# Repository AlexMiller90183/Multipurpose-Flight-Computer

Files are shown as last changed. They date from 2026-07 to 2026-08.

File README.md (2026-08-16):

Multipurpose Flight Computer
============================
This project is a flight computer designed to be used for many purposes, whether it be RC airplanes, model rockets, or even drones. Because of the broad usage capability it's designed to be as small as possible. It includes a barometer, IMU, servo outputs, and a battery controller. It is all powered by the STM32



PCB:
====
Schematic:
opdf-1





Why this?
=========
Well there I was... sitting bored at home

Just kidding. I previously made an Arduino Nano based flight computer with premade components and it was my first ever PCB! As I've learned more though, I wanted to challenge myself with something a little more complex and this was the perfect idea! I followed @NotARoomba's tutorial, but tried to make my version as small and compact as possible.

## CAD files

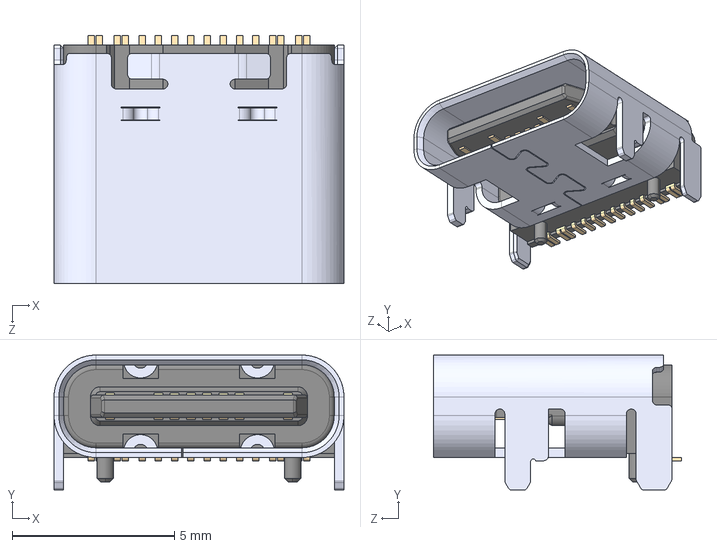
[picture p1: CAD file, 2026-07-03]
external 3d models/TYPE-C 16PIN 2MD -073---3DModel-STEP-740413.STEP
8.94 x 4.16 x 7.65 mm

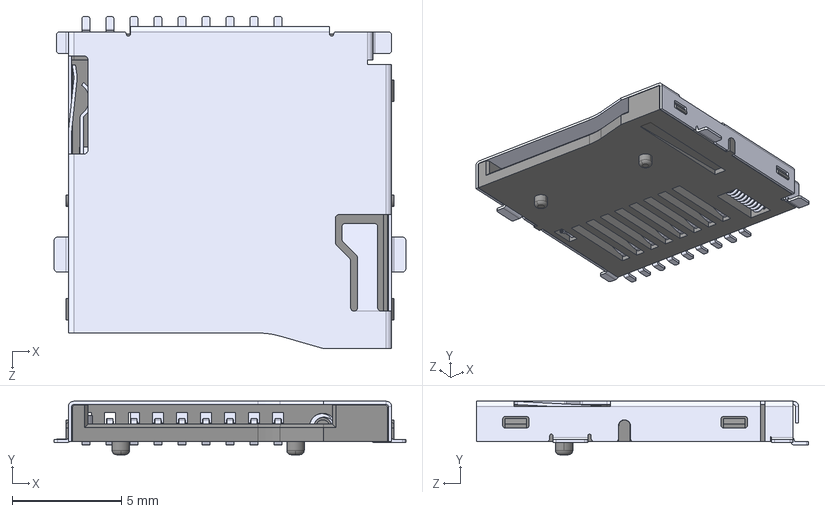
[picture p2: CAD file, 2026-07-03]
external 3d models/TF-01A--3DModel-STEP-56544.STEP
16.1 x 2.45 x 15.2 mm

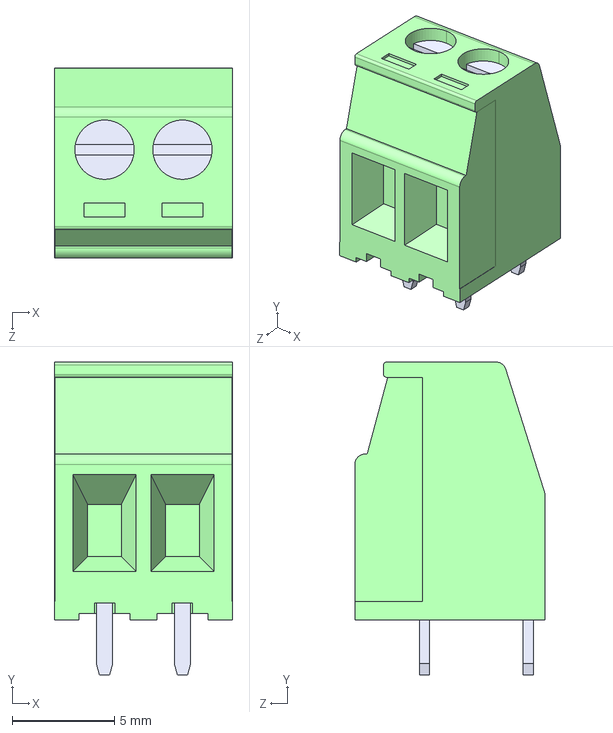
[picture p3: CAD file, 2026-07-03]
external 3d models/MKDS 1_ 2-3.81.STEP
8.71 x 15.3 x 9.30 mm

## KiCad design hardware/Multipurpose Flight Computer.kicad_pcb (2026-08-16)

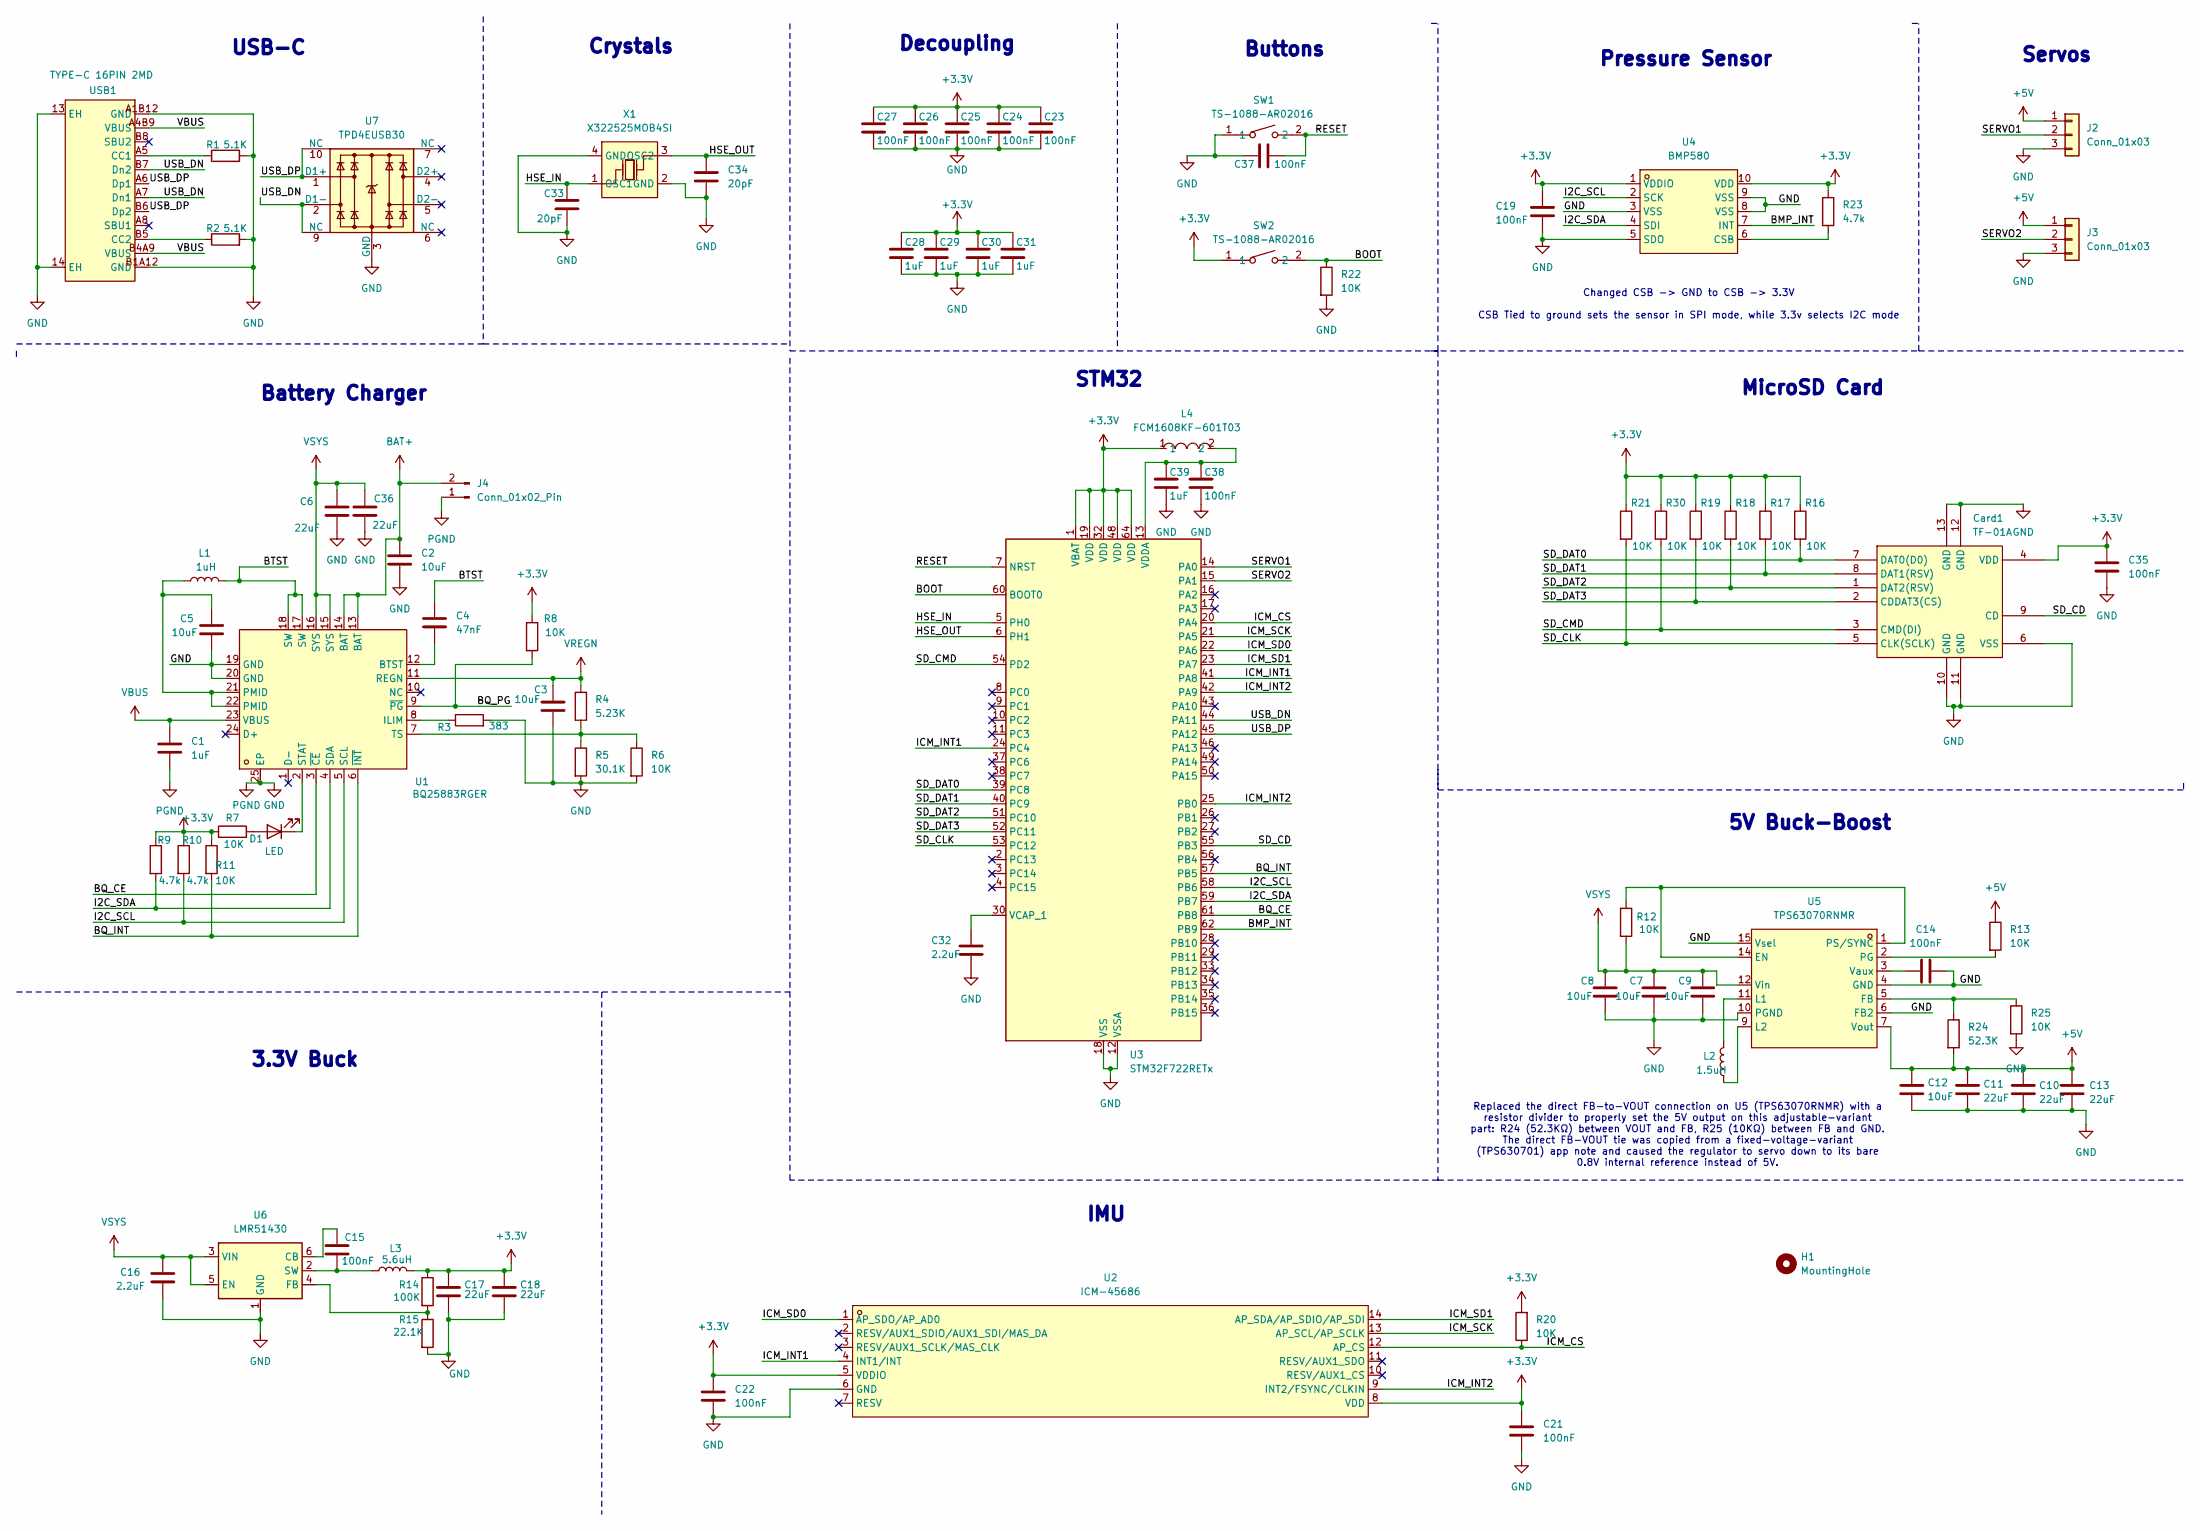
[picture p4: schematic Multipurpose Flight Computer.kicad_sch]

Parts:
C1, C28, C29, C30, C31, C39: 1uF; C_0402_1005Metric
C2, C12: 10uF; C_0603_1608Metric
C3, C5: 10uF; C_0402_1005Metric
C4: 47nF; C_0201_0603Metric
C6, C36: 22uF; C_0603_1608Metric
C7, C8, C9: 10uF; C_0805_2012Metric
C10, C11, C13: 22uF; C_0805_2012Metric
C14, C15, C19, C21, C22, C23, C24, C25, C26, C27, C35, C37, C38: 100nF; C_0201_0603Metric
C16: 2.2uF; C_0603_1608Metric
C17, C18: 22uF; C_0402_1005Metric
C32: 2.2uF; C_0201_0603Metric
C33, C34: 20pF; C_0201_0603Metric
Card1: TF-01A; TF-SMD_TF-01A; MPN TF-01A; LCSC Part C91145
D1: LED; LED_0402_1005Metric
H1: MountingHole; MountingHole_2.2mm_M2_DIN965_Pad_TopBottom
J2, J3: Conn_01x03; PinHeader_1x03_P2.54mm_Vertical
J4: Conn_01x02_Pin; CONN-TH_XT30PW-M
L1: 1uH; L2520
L2: 1.5uH; IND-SMD_L4.0-W4.0-A
L3: 5.6uH; IND-SMD_L3.0-W3.0
L4: FCM1608KF-601T03; L0603; MPN FCM1608KF-601T03; LCSC Part C141723
R1, R2: 5.1K; R_0201_0603Metric
R3: 383; R_0603_1608Metric
R4: 5.23K; R_0201_0603Metric
R5: 30.1K; R_0402_1005Metric
R6, R7, R8, R11, R12, R13, R16, R17, R18, R19, R20, R21, R22, R25, R30: 10K; R_0201_0603Metric
R9, R10, R23: 4.7k; R_0201_0603Metric
R14: 100K; R_0402_1005Metric
R15: 22.1K; R_0402_1005Metric
R24: 52.3K; R_0201_0603Metric
SW1, SW2: TS-1088-AR02016; SW-SMD_L3.9-W3.0-P4.45; MPN TS-1088-AR02016; LCSC Part C720477
U1: BQ25883RGER; VFQFPN-24_L4.0-W4.0-P0.50-BL-EP2.8; MPN BQ25883RGER; LCSC Part C544362
U2: ICM-45686; LGA-14_L3.0-W2.5-P0.50-TL; MPN ICM-45686; LCSC Part C22459454
U3: STM32F722RETx; LQFP-64_10x10mm_P0.5mm
U4: BMP580; LGA-10_L2.0-W2.0-P0.50-TL_BMP580; MPN BMP580; LCSC Part C22391138
U5: TPS63070RNMR; VQFN-15_L3.0-W2.5-P0.50-BL; MPN TPS63070RNMR; LCSC Part C109322
U6: LMR51430; SOT-23-6
U7: TPD4EUSB30; USON-10_2.5x1.0mm_P0.5mm
USB1: TYPE-C 16PIN 2MD; USB-C-SMD_TYPE-C-16PIN-2MD-073; MPN TYPE-C 16PIN 2MD(073); LCSC Part C2765186
X1: X322525MOB4SI; CRYSTAL-SMD_4P-L3.2-W2.5-BL; MPN X322525MOB4SI; LCSC Part C9006

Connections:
+3.3V: C17.1, C18.1, C19.1, C21.1, C22.1, C23.1, C24.1, C25.1, C26.1, C27.1, C28.1, C29.1, C30.1, C31.1, C35.2, Card1.4 (VDD), L3.2, L4.1, R7.1, R8.1, R9.1, R10.1, R11.1, R14.1, R16.1, R17.1, R18.1, R19.1, R20.2, R21.1, R23.1, R30.1, SW2.1, U2.5 (VDDIO), U2.8 (VDD), U3.1 (VBAT), U3.19 (VDD), U3.32 (VDD), U3.48 (VDD), U3.64 (VDD), U4.1 (VDDIO), U4.10 (VDD)
+5V: C10.1, C11.1, C12.1, C13.1, J2.1, J3.1, R13.1, R24.2, U5.7 (Vout)
/BMP_INT: U3.62 (PB9), U4.7 (INT)
/BOOT: R22.1, SW2.2, U3.60 (BOOT0)
/BQ_CE: U1.3 (~CE), U3.61 (PB8)
/BQ_INT: R11.2, U1.6 (~INT), U3.57 (PB5)
/BQ_PG: R8.2, U1.9 (~PG)
/BTST: C4.1, L1.2, U1.17 (SW), U1.18 (SW)
/HSE_IN: C33.1, U3.5 (PH0), X1.1 (OSC1)
/HSE_OUT: C34.1, U3.6 (PH1), X1.3 (OSC2)
/I2C_SCL: R10.2, U1.5 (SCL), U3.58 (PB6), U4.2 (SCK)
/I2C_SDA: R9.2, U1.4 (SDA), U3.59 (PB7), U4.4 (SDI)
/ICM_CS: R20.1, U2.12 (AP_CS), U3.20 (PA4)
/ICM_INT1: U2.4 (INT1/INT), U3.24 (PC4), U3.41 (PA8)
/ICM_INT2: U2.9 (INT2/FSYNC/CLKIN), U3.25 (PB0), U3.42 (PA9)
/ICM_SCK: U2.13 (AP_SCL/AP_SCLK), U3.21 (PA5)
/ICM_SD0: U2.1 (AP_SDO/AP_AD0), U3.22 (PA6)
/ICM_SD1: U2.14 (AP_SDA/AP_SDIO/AP_SDI), U3.23 (PA7)
/RESET: C37.1, SW1.2, U3.7 (NRST)
/SD_CD: Card1.9 (CD), U3.55 (PB3)
/SD_CLK: Card1.5 (CLK(SCLK)), R21.2, U3.53 (PC12)
/SD_CMD: Card1.3 (CMD(DI)), R30.2, U3.54 (PD2)
/SD_DAT0: Card1.7 (DAT0(D0)), R16.2, U3.39 (PC8)
/SD_DAT1: Card1.8 (DAT1(RSV)), R17.2, U3.40 (PC9)
/SD_DAT2: Card1.1 (DAT2(RSV)), R18.2, U3.51 (PC10)
/SD_DAT3: Card1.2 (CDDAT3(CS)), R19.2, U3.52 (PC11)
/SERVO1: J2.2, U3.14 (PA0)
/SERVO2: J3.2, U3.15 (PA1)
/USB_DN: U3.44 (PA11), U7.2 (D1-), U7.9 (NC), USB1.A7 (Dn1), USB1.B7 (Dn2)
/USB_DP: U3.45 (PA12), U7.1 (D1+), U7.10 (NC), USB1.A6 (Dp1), USB1.B6 (Dp2)
BAT+: C2.1, J4.2, U1.13 (BAT), U1.14 (BAT)
GND: C1.2, C2.2, C3.2, C5.2, C6.2, C7.2, C8.2, C9.2, C10.2, C11.2, C12.2, C13.2, C14.2, C16.2, C17.2, C18.2, C19.2, C21.2, C22.2, C23.2, C24.2, C25.2, C26.2, C27.2, C28.2, C29.2, C30.2, C31.2, C32.2, C33.2, C34.2, C35.1, C36.2, C37.2, C38.2, C39.2, Card1.6 (VSS), Card1.10 (GND), Card1.11 (GND), Card1.12 (GND), Card1.13 (GND), J2.3, J3.3, J4.1, R1.2, R2.2, R3.2, R5.2, R6.2, R15.2, R22.2, R25.2, SW1.1, U1.19 (GND), U1.20 (GND), U1.25 (EP), U2.6 (GND), U3.12 (VSSA), U3.18 (VSS), U3.31 (VSS), U3.47 (VSS), U3.63 (VSS), U4.3 (VSS), U4.5 (SDO), U4.8 (VSS), U4.9 (VSS), U5.4 (GND), U5.6 (FB2), U5.10 (PGND), U5.15 (Vsel), U6.1 (GND), U7.3 (GND), U7.8 (GND), USB1.13 (EH), USB1.14 (EH), USB1.A1B12 (GND), USB1.B1A12 (GND), X1.2 (GND), X1.4 (GND)
unnamed: C5.1, L1.1, U1.21 (PMID), U1.22 (PMID)
unnamed: D1.2 (A), R7.2
unnamed: D1.1 (K), U1.2 (STAT)
unnamed: C4.2, U1.12 (BTST)
unnamed: R3.1, U1.8 (ILIM)
unnamed: R4.2, R5.1, R6.1, U1.7 (TS)
unnamed: C32.1, U3.30 (VCAP_1)
unnamed: C38.1, C39.1, L4.2, U3.13 (VDDA)
unnamed: R23.2, U4.6 (CSB)
unnamed: R12.1, U5.1 (PS/SYNC), U5.14 (EN)
unnamed: R24.1, R25.1, U5.5 (FB)
unnamed: L2.2, U5.11 (L1)
unnamed: L2.1, U5.9 (L2)
unnamed: R13.2, U5.2 (PG)
unnamed: C14.1, U5.3 (Vaux)
unnamed: C15.1, U6.6 (CB)
unnamed: R14.2, R15.1, U6.4 (FB)
unnamed: C15.2, L3.1, U6.2 (SW)
unnamed: R1.1, USB1.A5 (CC1)
unnamed: R2.1, USB1.B5 (CC2)
VBUS: C1.1, U1.23 (VBUS), USB1.A4B9 (VBUS), USB1.B4A9 (VBUS)
VREGN: C3.1, R4.1, U1.11 (REGN)
VSYS: C6.1, C7.1, C8.1, C9.1, C16.1, C36.1, R12.2, U1.15 (SYS), U1.16 (SYS), U5.12 (Vin), U6.3 (VIN), U6.5 (EN)

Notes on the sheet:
STM32
Crystals
3.3V Buck
USB-C
Replaced the direct FB-to-VOUT connection on U5 (TPS63070RNMR) with a resistor divider to properly set the 5V output on this adjustable-variant part: R24 (52.3KΩ) between VOUT and FB, R25 (10KΩ) between FB and GND. The direct FB-VOUT tie was copied from a fixed-voltage-variant (TPS630701) app note 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
IMU
MicroSD Card
Servos
Decoupling
Battery Charger
Buttons
5V Buck-Boost
Changed CSB -> GND to CSB -> 3.3V CSB Tied to ground sets the sensor in SPI mode, while 3.3v selects I2C mode
Pressure Sensor

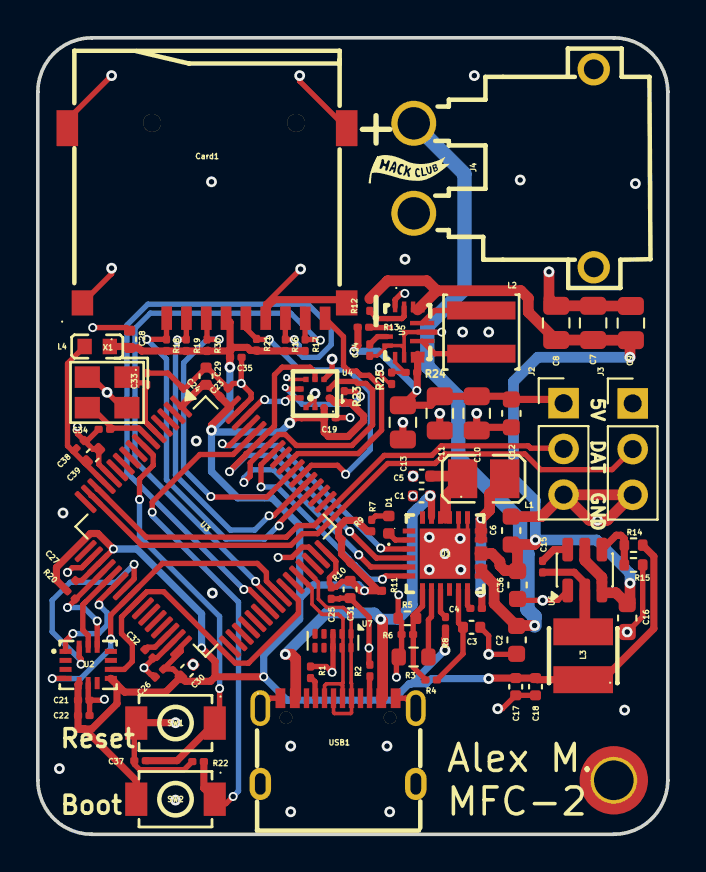
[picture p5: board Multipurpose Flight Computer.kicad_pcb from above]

Board: 4 copper layers, 35.0 x 44.3 mm, 85 parts (0 on the bottom side), 55 nets.

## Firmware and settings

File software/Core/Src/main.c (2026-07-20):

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
/* Includes ------------------------------------------------------------------*/
#include "main.h"
#include "fatfs.h"
#include "usb_device.h"

/* USER CODE BEGIN Includes */

#include "usbd_cdc_if.h"
#include <stdio.h>
#include "fatfs.h"
#include <stdio.h>
#include <string.h>

/* USER CODE END Includes */


I2C_HandleTypeDef hi2c1;

SD_HandleTypeDef hsd1;

SPI_HandleTypeDef hspi1;

TIM_HandleTypeDef htim2;

/* USER CODE BEGIN PV */

FATFS fs;

/* USER CODE END PV */

void SystemClock_Config(void);
static void MPU_Config(void);
static void MX_GPIO_Init(void);
static void MX_I2C1_Init(void);
static void MX_SPI1_Init(void);
static void MX_SDMMC1_SD_Init(void);
static void MX_TIM2_Init(void);
/* USER CODE BEGIN PFP */

uint8_t ICM_SPI_Read(uint8_t reg);
void ICM_SPI_Write(uint8_t reg, uint8_t value);
void TestICMRegisters(void);
int16_t ICM_ReadAccelX(void);

/* USER CODE END PFP */

/* USER CODE BEGIN 0 */

void ICM_DumpRegisters(void)
{
    for(uint8_t i = 0; i < 0x20; i++)
    {
        printf("REG 0x%02X = 0x%02X\r\n",
               i,
               ICM_SPI_Read(i));
    }
}

void I2C_Scan(void)
{
    HAL_StatusTypeDef result;

    printf("Starting I2C scan...\r\n");

    for(uint8_t addr = 1; addr < 127; addr++)
    {
        printf("Checking 0x%02X\r\n", addr);

        result = HAL_I2C_IsDeviceReady(&hi2c1,
                                       addr << 1,
                                       3,
                                       100);

        printf("Result=%d\r\n", result);

        if(result == HAL_OK)
        {
            printf("Found device at 0x%02X\r\n", addr);
        }

        HAL_Delay(5);
    }

    printf("Done\r\n");
}

void ICM_Init(void)
{
    uint8_t data;

    printf("Initializing ICM45686\r\n");

    // Read WHO_AM_I
    data = ICM_SPI_Read(0x72);

    printf("WHO_AM_I = 0x%02X\r\n", data);


    // Soft reset
    ICM_SPI_Write(0x02, 0x01);

    HAL_Delay(50);


    // Power management
    ICM_SPI_Write(0x10, 0x0F);

    HAL_Delay(20);

    printf("ICM initialized\r\n");
}

void ICM_SPI_Write(uint8_t reg, uint8_t value)
{
    uint8_t tx[2];

    tx[0] = reg & 0x7F;   // SPI write
    tx[1] = value;


    HAL_GPIO_WritePin(GPIOA, GPIO_PIN_4, GPIO_PIN_RESET);

    HAL_SPI_Transmit(&hspi1,
                     tx,
                     2,
                     100);

    HAL_GPIO_WritePin(GPIOA, GPIO_PIN_4, GPIO_PIN_SET);
}

void Sensor_Check(void)
{
    uint8_t devices[] = {
        0x6B
    };

    printf("Checking sensors...\r\n");

    for(uint8_t i = 0; i < sizeof(devices); i++)
    {
        HAL_StatusTypeDef result;

        result = HAL_I2C_IsDeviceReady(&hi2c1, devices[i] << 1, 5, 100);

        if(result == HAL_OK)
        {
            printf("Sensor found at 0x%02X\r\n", devices[i]);
        }
        else
        {
            printf("No response at 0x%02X (HAL error %d)\r\n",
                   devices[i],
                   result);
        }
    }

    printf("Sensor check complete\r\n");
}

void SPI_Test(void)
{
    uint8_t tx[2];
    uint8_t rx[2];

    printf("Starting SPI test\r\n");

    // CS low
    HAL_GPIO_WritePin(GPIOA, GPIO_PIN_4, GPIO_PIN_RESET);

    // ICM45686 SPI read:
    // Register address ORed with 0x80
    tx[0] = 0x72 | 0x80;
    tx[1] = 0x00;

    HAL_StatusTypeDef status =
        HAL_SPI_TransmitReceive(&hspi1,
                                tx,
                                rx,
                                2,
                                100);

    // CS high
    HAL_GPIO_WritePin(GPIOA, GPIO_PIN_4, GPIO_PIN_SET);


    if(status != HAL_OK)
    {
        printf("SPI failed: %d\r\n", status);
        return;
    }

    printf("SPI RX: %02X %02X\r\n", rx[0], rx[1]);
}

void TestICM45686(void)
{
    uint8_t reg = 0x72;
    uint8_t value = 0;

    printf("Reading ICM WHO_AM_I\r\n");

    if(HAL_I2C_Master_Transmit(&hi2c1,
                               0x6B << 1,
                               &reg,
                               1,
                               100) != HAL_OK)
    {
        printf("Register address write failed\r\n");
        return;
    }

    if(HAL_I2C_Master_Receive(&hi2c1,
                              0x6B << 1,
                              &value,
                              1,
                              100) != HAL_OK)
    {
        printf("Read failed\r\n");
        return;
    }

    printf("WHO_AM_I = 0x%02X\r\n", value);
}

void ReadBank(void)
{
    uint8_t value;

    HAL_I2C_Mem_Read(&hi2c1,
                     0x6B << 1,
                     0x76,
                     I2C_MEMADD_SIZE_8BIT,
                     &value,
                     1,
                     100);

    printf("BANK = 0x%02X\r\n", value);
}

void SD_Test(void)
{
    FIL file;
    FRESULT result;
    UINT bytesWritten;

    printf("Starting SD test\r\n");

    printf("SD state: %lu\r\n", HAL_SD_GetCardState(&hsd1));

    printf("Before mount\r\n");

    result = f_mount(&fs, "", 1);

    printf("After mount: %d\r\n", result);

    printf("Mount result: %d\r\n", result);

    if(result != FR_OK)
    {
        return;
    }

    printf("Mount OK\r\n");


    result = f_open(&file, "test.txt", FA_CREATE_ALWAYS | FA_WRITE);

    printf("Open result: %d\r\n", result);

    if(result != FR_OK)
    {
        return;
    }


    char text[] = "STM32 Flight Computer SD Test\r\n";


    result = f_write(&file,
                     text,
                     strlen(text),
                     &bytesWritten);


    printf("Write result: %d bytes=%u\r\n",
           result,
           bytesWritten);


    f_close(&file);

    printf("Done\r\n");
}

void TestICMRegisters(void)
{
    uint8_t whoami;
    uint8_t bank;
    uint8_t status;

    whoami = ICM_SPI_Read(0x72);
    bank   = ICM_SPI_Read(0x76);
    status = ICM_SPI_Read(0x2D);

    printf("WHO_AM_I: 0x%02X\r\n", whoami);
    printf("BANK:     0x%02X\r\n", bank);
    printf("STATUS:   0x%02X\r\n", status);
}

uint8_t ICM_SPI_Read(uint8_t reg)
{
    uint8_t tx[2];
    uint8_t rx[2];

    tx[0] = reg | 0x80; // SPI read
    tx[1] = 0x00;

    HAL_GPIO_WritePin(GPIOA, GPIO_PIN_4, GPIO_PIN_RESET);

    HAL_SPI_TransmitReceive(&hspi1,
                            tx,
                            rx,
                            2,
                            100);

    HAL_GPIO_WritePin(GPIOA, GPIO_PIN_4, GPIO_PIN_SET);

    return rx[1];
}

int16_t ICM_ReadAccelX(void)
{
    uint8_t high;
    uint8_t low;

    high = ICM_SPI_Read(0x00);
    low  = ICM_SPI_Read(0x01);

    return ((int16_t)high << 8) | low;
}

void TestICM_SPI(void)
{
    uint8_t whoami;

    whoami = ICM_SPI_Read(0x72);

    printf("SPI WHO_AM_I = 0x%02X\r\n", whoami);
}

/* USER CODE END 0 */

/**
  * @brief  The application entry point.
  * @retval int
  */
int main(void)
{

  /* MPU Configuration--------------------------------------------------------*/
  MPU_Config();

  /* MCU Configuration--------------------------------------------------------*/

  /* Reset of all peripherals, Initializes the Flash interface and the Systick. */
  HAL_Init();

  /* Configure the system clock */
  SystemClock_Config();

  /* Initialize all configured peripherals */
  MX_GPIO_Init();
  MX_I2C1_Init();
  MX_SPI1_Init();
  MX_SDMMC1_SD_Init();
  MX_TIM2_Init();
  MX_USB_DEVICE_Init();
  MX_FATFS_Init();
  /* USER CODE BEGIN 2 */

  HAL_Delay(1000);   // give USB time to enumerate
  
  HAL_GPIO_WritePin(GPIOA, GPIO_PIN_0, GPIO_PIN_SET);
  HAL_Delay(10);

  I2C_Scan();
  Sensor_Check();
  TestICM45686();
  ReadBank();

  ICM_Init();
  ICM_DumpRegisters();
  
  /* USER CODE END 2 */

  /* Infinite loop */
  /* USER CODE BEGIN WHILE */
  while (1)
  {
    /* USER CODE END WHILE */

    /* USER CODE BEGIN 3 */


    int16_t accel_x = ICM_ReadAccelX();

    printf("Accel X = %d\r\n", accel_x);

    HAL_Delay(100);

  }
  /* USER CODE END 3 */
}

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
/* USER CODE BEGIN 4 */

int _write(int file, char *ptr, int len)
{
    if (CDC_Transmit_FS((uint8_t*)ptr, len) == USBD_OK)
    {
        return len;
    }

    return 0;
}

/* USER CODE END 4 */

 /* MPU Configuration */

void MPU_Config(void)
{
  MPU_Region_InitTypeDef MPU_InitStruct = {0};

  /* Disables the MPU */
  HAL_MPU_Disable();

  /** Initializes and configures the Region and the memory to be protected
  */
  MPU_InitStruct.Enable = MPU_REGION_ENABLE;
  MPU_InitStruct.Number = MPU_REGION_NUMBER0;
  MPU_InitStruct.BaseAddress = 0x0;
  MPU_InitStruct.Size = MPU_REGION_SIZE_4GB;
  MPU_InitStruct.SubRegionDisable = 0x87;
  MPU_InitStruct.TypeExtField = MPU_TEX_LEVEL0;
  MPU_InitStruct.AccessPermission = MPU_REGION_NO_ACCESS;
  MPU_InitStruct.DisableExec = MPU_INSTRUCTION_ACCESS_DISABLE;
  MPU_InitStruct.IsShareable = MPU_ACCESS_SHAREABLE;
  MPU_InitStruct.IsCacheable = MPU_ACCESS_NOT_CACHEABLE;
  MPU_InitStruct.IsBufferable = MPU_ACCESS_NOT_BUFFERABLE;

  HAL_MPU_ConfigRegion(&MPU_InitStruct);
  /* Enables the MPU */
  HAL_MPU_Enable(MPU_PRIVILEGED_DEFAULT);

}

/**
  * @brief  This function is executed in case of error occurrence.
  * @retval None
  */
void Error_Handler(void)
{
  /* USER CODE BEGIN Error_Handler_Debug */
  /* User can add his own implementation to report the HAL error return state */
  __disable_irq();
  while (1)
  {
  }
  /* USER CODE END Error_Handler_Debug */
}
#ifdef USE_FULL_ASSERT
/**
  * @brief  Reports the name of the source file and the source line number
  *         where the assert_param error has occurred.
  * @param  file: pointer to the source file name
  * @param  line: assert_param error line source number
  * @retval None
  */
void assert_failed(uint8_t *file, uint32_t line)
{
  /* USER CODE BEGIN 6 */
  /* User can add his own implementation to report the file name and line number,
     ex: printf("Wrong parameters value: file %s on line %d\r\n", file, line) */
  /* USER CODE END 6 */
}
#endif /* USE_FULL_ASSERT */

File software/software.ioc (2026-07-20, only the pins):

Mcu.UserName=STM32F722RETx
PA0-WKUP.Signal=GPIO_Output
PA1.Signal=S_TIM2_CH2
PA11.Signal=USB_OTG_FS_DM
PA12.Signal=USB_OTG_FS_DP
PA4.Signal=GPIO_Output
PA5.Signal=SPI1_SCK
PA6.Signal=SPI1_MISO
PA7.Signal=SPI1_MOSI
PB0.GPIO_Label=ICM_INT2
PB0.Signal=GPXTI0
PB3.GPIO_Label=SD_CS
PB3.Signal=GPIO_Input
PB5.GPIO_Label=BQ_INT
PB5.Signal=GPXTI5
PB6.Signal=I2C1_SCL
PB7.Signal=I2C1_SDA
PB8.GPIO_Label=BQ_CE
PB8.Signal=GPIO_Output
PB9.GPIO_Label=BMP_INT
PB9.Signal=GPXTI9
PC10.Signal=SDMMC1_D2
PC11.Signal=SDMMC1_D3
PC12.Signal=SDMMC1_CK
PC14-OSC32_IN.Signal=RCC_OSC32_IN
PC15-OSC32_OUT.Signal=RCC_OSC32_OUT
PC4.GPIO_Label=ICM_INT1
PC4.Signal=GPXTI4
PC8.Signal=SDMMC1_D0
PC9.Signal=SDMMC1_D1
PD2.Signal=SDMMC1_CMD
PH0-OSC_IN.Signal=RCC_OSC_IN
PH1-OSC_OUT.Signal=RCC_OSC_OUT

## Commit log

2026-07-02 Created KiCad Project
    [Multipurpose Flight Computer.kicad_pcb, Multipurpose Flight Computer.kicad_sch]
2026-07-02 Adding Libraries to KiCad
2026-07-02 Importing STM32 parts
    [Multipurpose Flight Computer.kicad_sch]
2026-07-02 Assigning Footprints
    [Multipurpose Flight Computer.kicad_sch]
2026-07-03 Initialize README with project details and motivation
    Added project description, PCB schematics, and motivation for development.
2026-07-03 Updating KiCad
    [Multipurpose Flight Computer.kicad_pcb, Multipurpose Flight Computer.kicad_sch]
2026-07-03 Finishing Touches
    [MKDS 1_ 2-3.81.STEP, Multipurpose Flight Computer.kicad_pcb, Multipurpose Flight Computer.kicad_sch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]
2026-07-03 4-layer upgrade
    [Multipurpose Flight Computer.kicad_pcb, Multipurpose Flight Computer.kicad_sch]
2026-07-03 fixing drc
    [Multipurpose Flight Computer.kicad_pcb]
2026-07-03 minor edits
    [Multipurpose Flight Computer.kicad_pcb]
2026-07-04 Finalized Board Design
    [Multipurpose Flight Computer.kicad_pcb, Multipurpose Flight Computer.kicad_sch, bom.csv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]
2026-07-20 Bug Fixes
    [Multipurpose Flight Computer.kicad_pcb, Multipurpose Flight Computer.kicad_sch, bom.csv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]
2026-07-20 Added software
    [Multipurpose Flight Computer.kicad_pcb, Multipurpose Flight Computer.kicad_sch]
2026-08-16 Design Fixes
    [Multipurpose Flight Computer.kicad_pcb, Multipurpose Flight Computer.kicad_sch]

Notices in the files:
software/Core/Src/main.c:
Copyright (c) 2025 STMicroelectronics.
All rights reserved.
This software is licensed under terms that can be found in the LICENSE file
